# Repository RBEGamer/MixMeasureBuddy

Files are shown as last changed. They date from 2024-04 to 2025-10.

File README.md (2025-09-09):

# MixMeasureBuddy

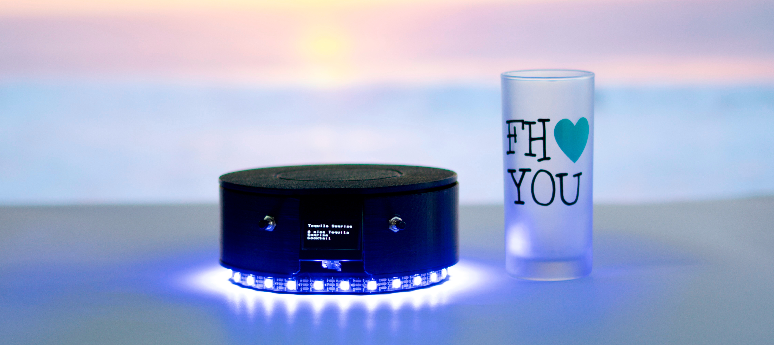
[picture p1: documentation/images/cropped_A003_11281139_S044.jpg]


MixMeasureBuddy's smart cocktail scale revolutionizes home bartending by offering accurate ingredient measurements and a vast library of cocktail recipes personalized to your liquor collection. Enjoy the art of mixology with ease and precision.

Discover the advanced features that set MixMeasureBuddy apart from traditional kitchen scales.

## FEATURES

Discover the advanced features that set MixMeasureBuddy apart from traditional kitchen scales:

* **Open-Source** MixMeasureBuddy is 100% open-source and can be build using a few simple and cheap parts.
* **Connectivity Features** Enjoy seamless integration with a companion webapp for sharing personalized cocktail recipes with other MixMeasureBuddy owners.
* **Offline Usage** Recipes are stored offline and locally on the MixMeasureBerry and can be edited using a text editor
* **User-Friendly Interface** Easily navigate the scale's intuitive interface for effortless cocktail making.
* **Customizable Recipes** Access a plethora of cocktail recipes tailored to your liquor cabinet for endless mixing possibilities.
* **Precision Measurements** Eliminate the guesswork and achieve consistent results with exact ingredient measurements every time.

## BOM

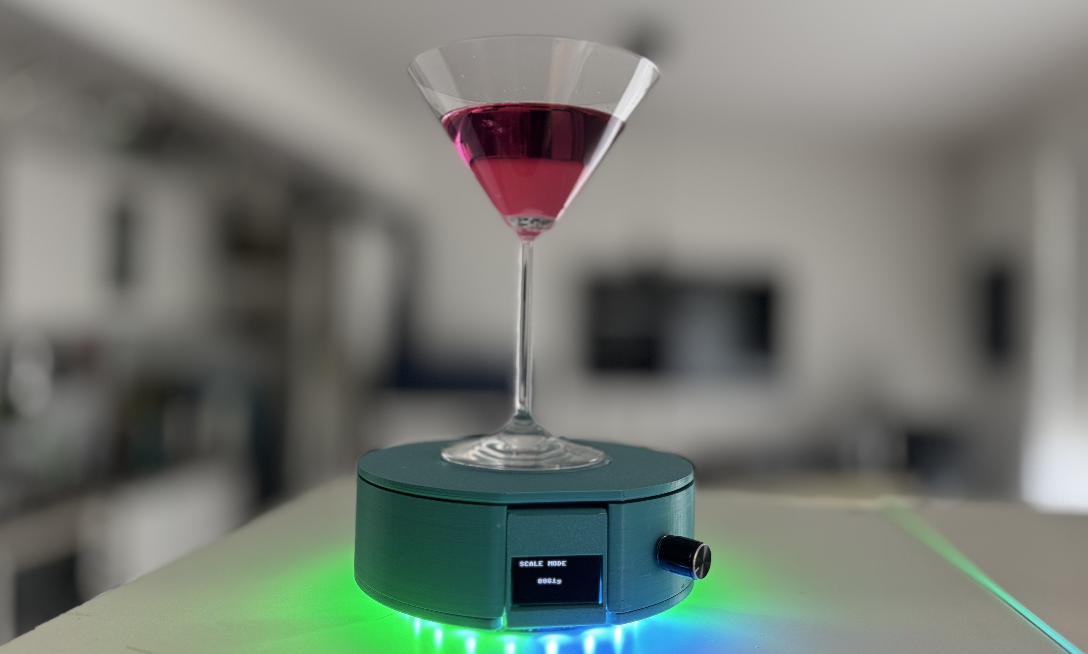
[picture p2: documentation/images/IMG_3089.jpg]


### 3D PRINTED PARTS

**Please read the 3d printing instructions before printing any part!**

* 1x `ring.stl`
* 1x `breadboard_mount.stl`
* 1x `inner_cellplate.stl`
* 1x `hinge.stl`
* 1x `bottom.stl`
* 1x `display_clamp.stl`
* 1x `display_mount.stl`
* 1x `encoder_clamp.stl`

#### CELLPLATE

* 1x `cellplate_<style>.stl`

The top plate exists in three different styles:

* `normal` - plain top plate
* `ring` - with an 82-84mm diameter ring depression in the center to plate a rubber band in it
* `plate` - with an 80mm diameter circular depression to place a rubber sheet in it

The `ring` and `plate` variants offer better grip of the glasses while standing on the platic top plate.

#### BOTTOM PLATE

If a `8mm` wide led strip is used please set the scale of `bottom.stl` to `120%` in **Z** direction.

#### 3D PRINT SETTINGS

* Layer height: `0.2` - `0.4`mm
* Support: `Support on buildplate only`
* Inflill: `20%`

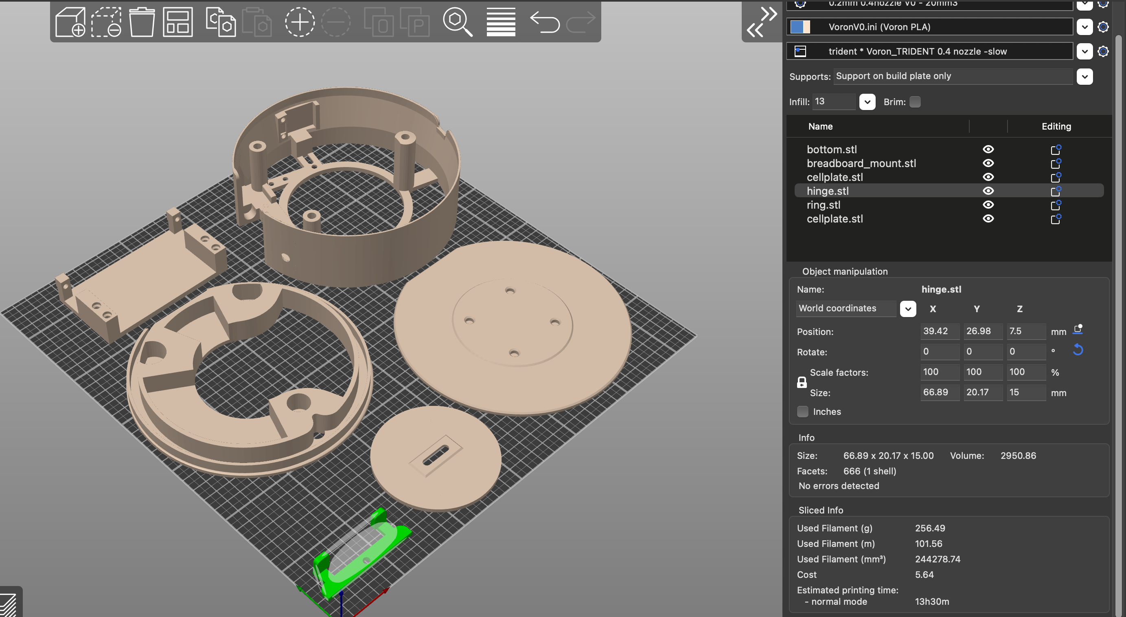
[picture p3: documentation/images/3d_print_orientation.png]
3D printed parts orientation on bed


### MECHANICAL

* 6x `Heat Inserts M3`
* 6x `M3x10 BHCS`
* 4x `M4x10 BHCS` - depends on load cell screw threads
* 3x `Heat Inserts M4`
* 3x `M4x10 BHCS`
* 8x `Cylindrical Magnet D5mm H8mm` or four additional `Heat Inserts M4` + four additional `M4x10 SHCS` to replace the magnets

### MISC

* `Super Glue` - to glue magnets into `inner_cellplate` and `cellplate`

### ELECTRICAL

* 1x `Raspberry Pi Pico` or `Raspberry Pi Pico W`
* 1x `LOAD CELL` with dimensions of `60x12x12mm` and at least `2kg`, for example `YZC-131`
* 1x `HX711`
* 1x `1.3" I2C OLED SSH1306`
* 1x `Encoder` e.g. `KY-040`
* 50cm `WS2812` strip
* Jumperwires  >12x `male-male`, >10x `male-female`
* 1x Breadboard with dimensions of `83 x 55mm`, for example `Mini Breadboard 400 Pin`
* [OPTIONAL] `SPI SD TF Karte Memory Card Shield Modul`
* [OPTIONAL] `Battery Expansion Shield 18650 V3`

### TOOLS

* `Soldering Iron`
* `Hotglue`

## HARDWARE BUILD

### SCHEMATIC

The following diagram shows the internal wiring of the individual components of the `MixMeasureBuddy`.
Only the `Raspberry Pi Pico`, button and the `HX711` are placed on the small breadboard.
The display, `LEDs` and the encoder(-module) are connected with longer cables so that they can be attached to the 3D printed parts at the intended mounting locations.

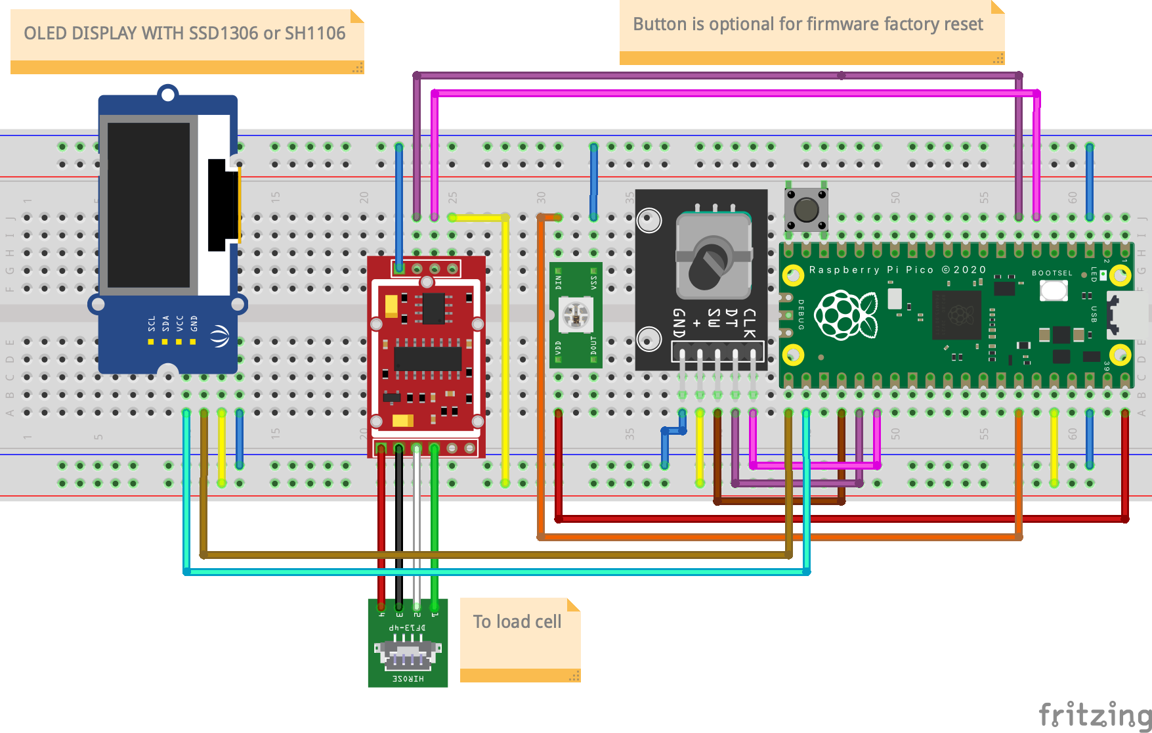
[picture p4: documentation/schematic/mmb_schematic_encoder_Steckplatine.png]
MixMeasureBuddy Schematic


The circuit diagram was created in the Fritzing software. The project can be found under `documenation/schematic/`.
After the function of all parts has been tested, the connections on the breadboard should be fixed with hot glue so that they do not come loose during transportation.

### NOTES

To fix accuracy issues on several `HX711` boards, two addional resistors are needed.
Please refer to this guide: [HX711 – Auswahl und Beschaltung](https://beelogger.de/sensoren/waegezellen_hx711/hx711_beschaltung/#:~:text=HX711%20Modul%20Auswahl,Wägezelle%20und%20einen%20einstellbaren%20Messbrückenverstärker.)

#### [OPTIONAL] SD CARD READER

It is possible to connect an additional SD card reader. This makes it possible to save the recipes on an SD card.  
Please connect the SD card reader to the following pins on the `Raspberry Pi Pico`:

| Raspberry Pi Pico GPIO | SD CARD MODULE GPIO |
|---|---|
| VCC (Pin 36) | 3V3 (OUT) / VCC |
| GND (Pin 18) | GND |
| GP10 | SCK |
| GP8 | MISO |
| GP11 | MOSI |
| GP9 | CS |

No further software changes are needed later on. The systems firmware detects the connected SD card automatically.

#### [OPTIONAL] BATTERY EXPANSION

The `Battery Expansion Shield 18650 V3` can be mounted on the `breadboard_mount.stl` later on.
In oder to connect the `Battery Expansion` to the `Raspberry Pi Pico GPIO` please follow the wiring table below:

| Raspberry Pi Pico GPIO | Battery Expansion |
|---|---|
| VBUS (Pin 40) | 5V OUT |
| GND  (Pin 38) | GND |

## SOFTWARE INSTALLATION

Please check the `Releases` page of this repository for prebuild firmware archives.

To initially flash the software to the `Raspberry Pi Pico`, the `BOOT` button must first be held down when plugging in the `USB` cable.
A new removable disk will then appear on the `PC`. The `firmware.uf2` is then copied to this.
The microcontroller will then restart and the MixMeasureBuddy logo should appear on the display.

If you want to build the software yourself from source or add modifications, please refer to the `SOFTWARE DEVELOPMENT` chapter.

**NOTE** There is an firmware archive with older stable versions located in `src/firmware/build/archive`.

### SOFTWARE UPGRADE

If a old version of the firmwre was already installed on the `Raspberry Pi Pico`, please flash the [flash_nuke.uf2](https://github.com/dwelch67/raspberrypi-pico/blob/main/flash_nuke.uf2) first! This clears all user settings!

**NOTE** Please backup all your stored recipes first!

## MECHANICAL BUILD

FINAL_ASSEMBLY

### 1. DISPLAY MOUNT

DISPLAY_MOUNT_WITH_HEAT_INSERT

* 1x `Heat Inserts M3`
* 1x `M3x10`
* 1x `1.3" I2C OLED SSH1306`
* 4x Jumperwires `male-female`
* 1x `display_clamp.stl`
* 1x `display_mount.stl`

#### INSTRUCTIONS

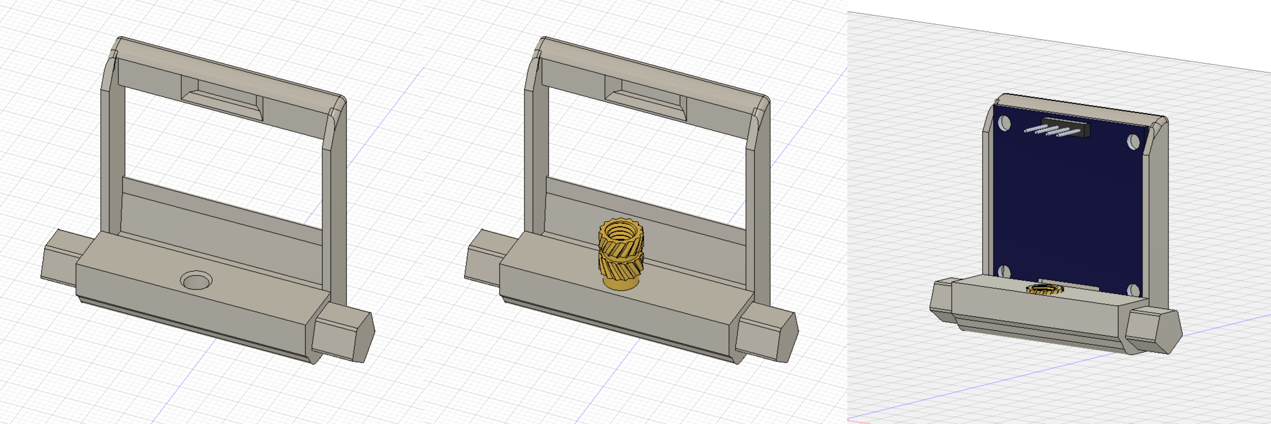
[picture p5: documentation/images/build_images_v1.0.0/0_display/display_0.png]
display_0


1. Insert the `M3 Heat Insert` using a soldering iron into `display_mount`
2. Place the `1.3" I2C OLED SSH1306` display inside `display_mount` 
3. Press the display into place using the `display_clamp` and one `M3x10`
4. Connect four `male-female` jumperwires onto the display header
5. Glue the jumperwire ends and the header together using a drop of hotgleue
6. [OPTIONAL] Lock down the jumperwires using a small zip-tie

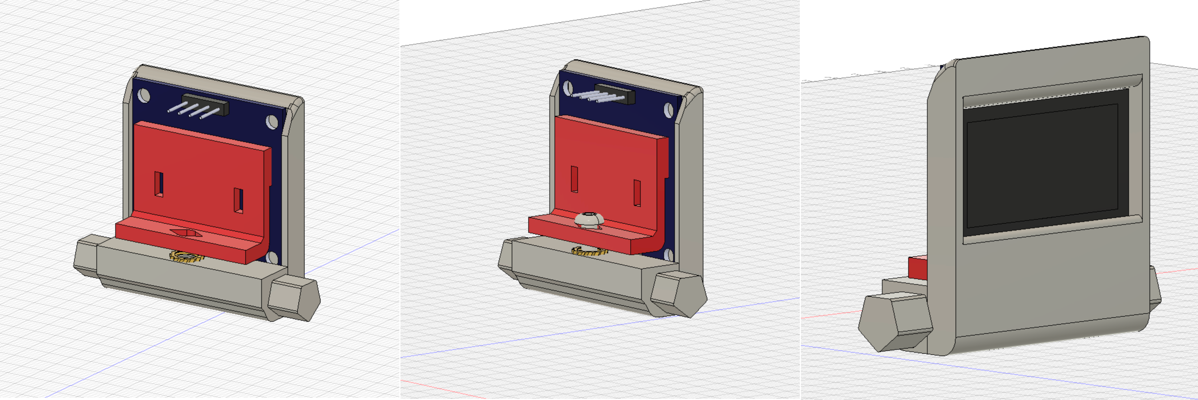
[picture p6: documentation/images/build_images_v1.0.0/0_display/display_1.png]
display_1


### 2. ENCODER MOUNT

* 2x `Heat Inserts M3`
* 1x `M3x10`
* 4x Jumperwires `male-female`
* 1x `Encoder` e.g. `KY-040`
* 1x `encoder_clamp.stl`
* 1x `ring.stl`

#### INSTRUCTIONS

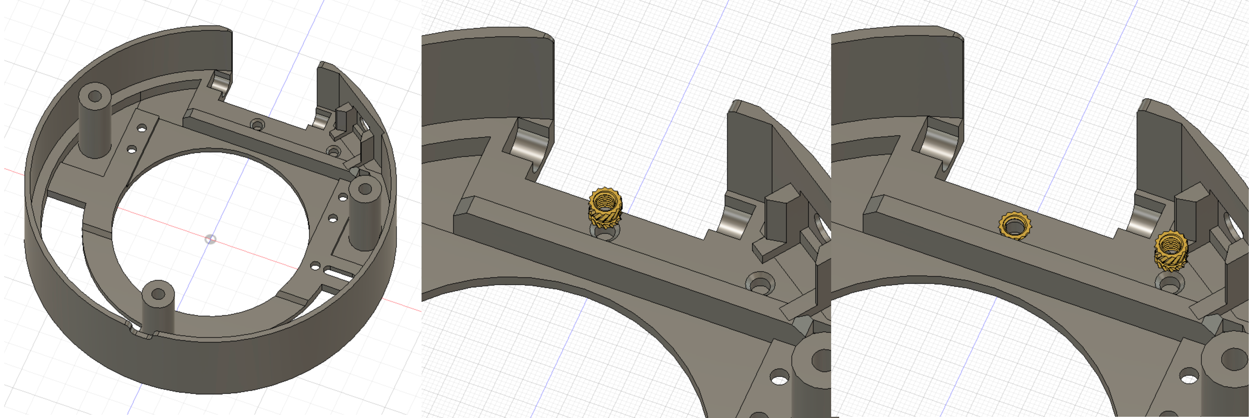
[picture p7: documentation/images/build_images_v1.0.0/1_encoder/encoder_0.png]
1_encoder


1. Connect five `male-female` jumperwires onto the encoder pcb header
2. Insert the two `M3 Heat Inserts` using a soldering iron into `ring` part
3. Insert the encoder pcb into `ring` shell
4. Use the `encoder_clamp` and one `M3x10` to press the encoder into the `ring`

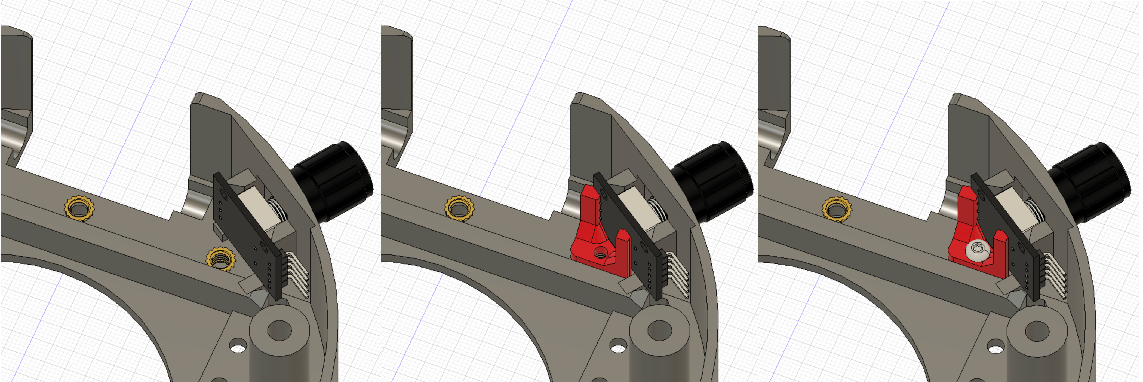
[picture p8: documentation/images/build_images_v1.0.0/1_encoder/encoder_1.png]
1_encoder


### 3. ASSEMBLE DISPLAY AND RING PARTS

* 1x `M3x10`
* 1x `hinge.stl`

#### INSTRUCTIONS

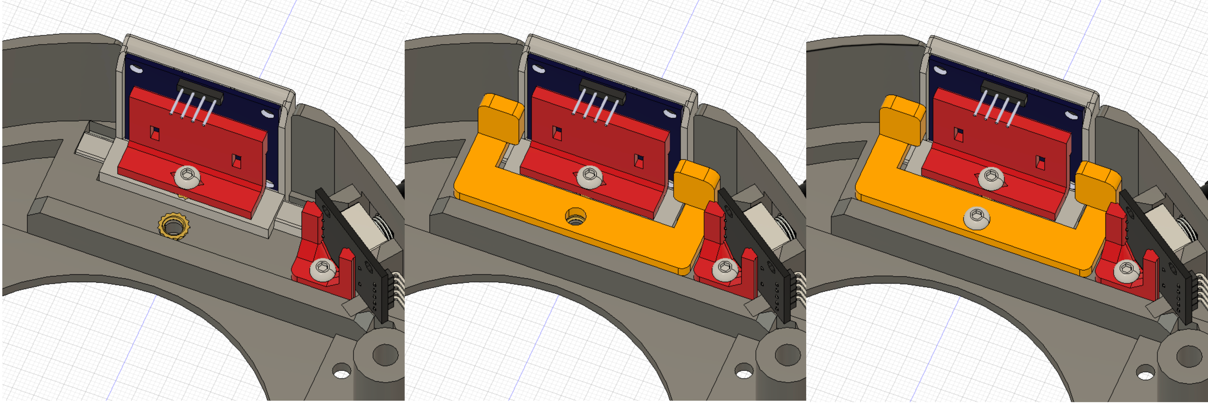
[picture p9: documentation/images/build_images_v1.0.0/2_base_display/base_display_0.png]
2_base_display
 

* Place the display assembly in the indentation
* Use the `hinge` and  one `M3x10` to press the assembly into the `ring`

### 3. LOADCELL

* 4x `M4x10` - depends on load cell screw threads
* 4x `Cylindrical Magnet D5mm H8mm`
* 1x `LOAD CELL`

* 1x `inner_cellplate.stl`

#### INSTRUCTIONS

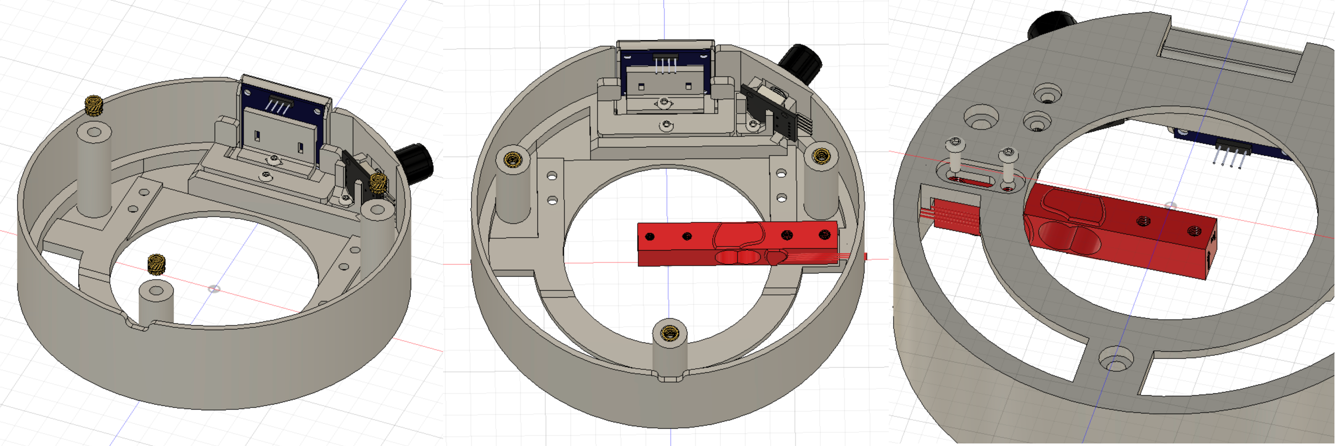
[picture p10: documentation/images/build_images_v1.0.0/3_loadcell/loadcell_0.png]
3_loadcell
 

1. Insert the three `M4 Heat Inserts` using a soldering iron into `ring` part
2. Screw the loadcell using two `M4x10` screws into the `ring`
3. Use the remaining `M4x10` screws to mount the `inner_cellplate` on the load cell arm, in the center of the `ring` cutout
4. Glue four magnets into `inner_cellplate`

**NOTE** The cables from the load cell are facing towards the shell of the `ring`

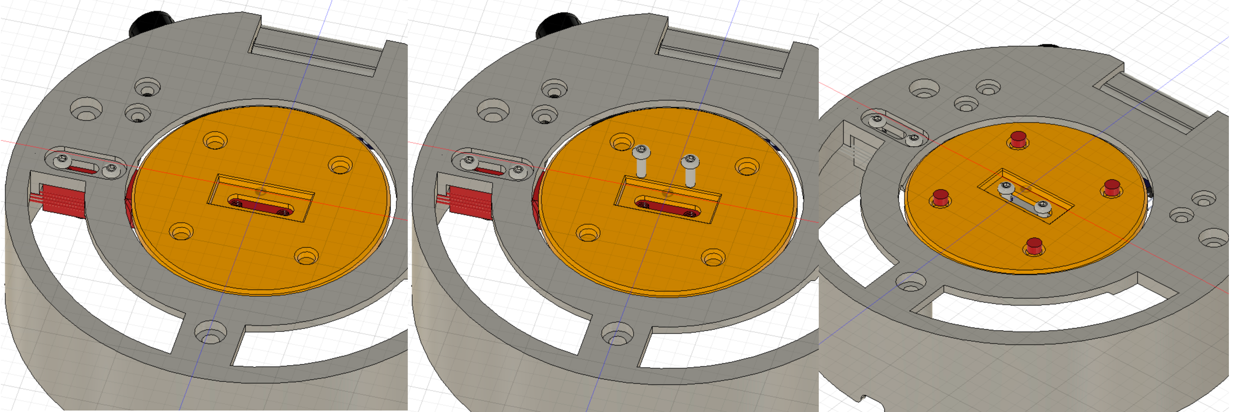
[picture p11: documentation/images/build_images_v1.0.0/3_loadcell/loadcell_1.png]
3_loadcell
 

### 4. BREADBOARD

ELECTRONICS_BAY_COMPONENTS

* 4x `Heat Inserts M3`
* 4x `M3x10 BHCS`
* 1x `ASSEMBLED BREADBOARD`
* 1x `breadboard_mount.stl`

#### INSTRUCTIONS

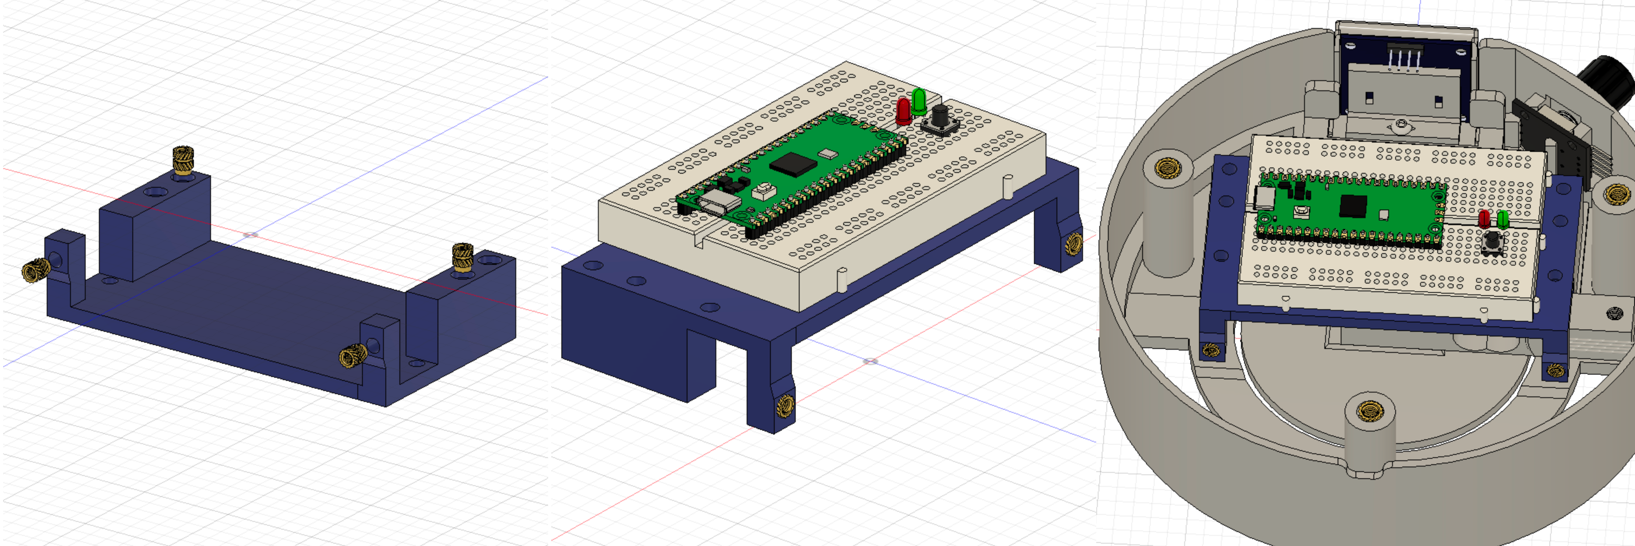
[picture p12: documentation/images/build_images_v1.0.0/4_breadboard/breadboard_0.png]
4_breadboard
 

1. Insert the four `M3 Heat Inserts` using a soldering iron into `breadboard_mount` part
2. [OPTIONAL] Screw the `Battery Expansion Shield 18650 V3` into the side using two `M3x10`
3. Remove the protective film from the breadboard bottom side and place it ontop `breadboard_mount`stl`
4. Use the remaining two `M3x10` screws to fix `breadboard_mount` and `ring` together into place

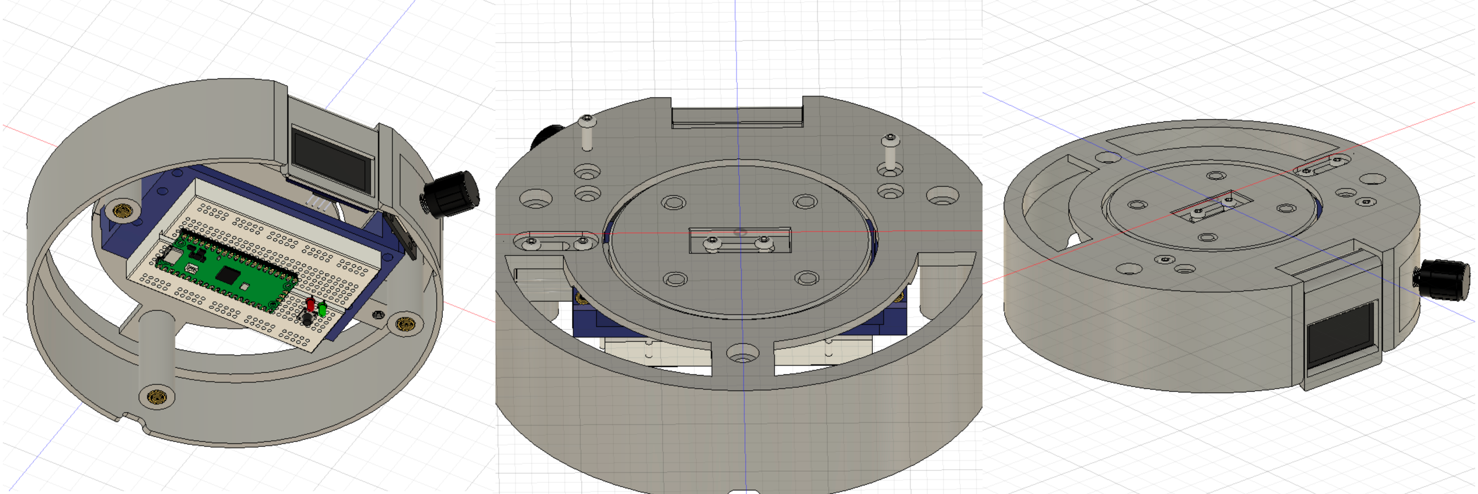
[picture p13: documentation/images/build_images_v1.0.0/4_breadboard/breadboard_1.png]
4_breadboard
 

**NOTE** Please connect all remaining components (`Encoder`, `Display`, ...) to the breadboard. See chapter `SCHEMATIC` again.
**NOTE** Its a good time to test the electronics again! Please refer to the `SOFTWARE INSTALLATION` chapter.

### 5. BOTTOM

* `WS2812` strip
* 3x `M4x10 SHCS`
* 3x  Jumperwire `male-male`
* 1x `bottom.stl`

#### INSTRUCTIONS

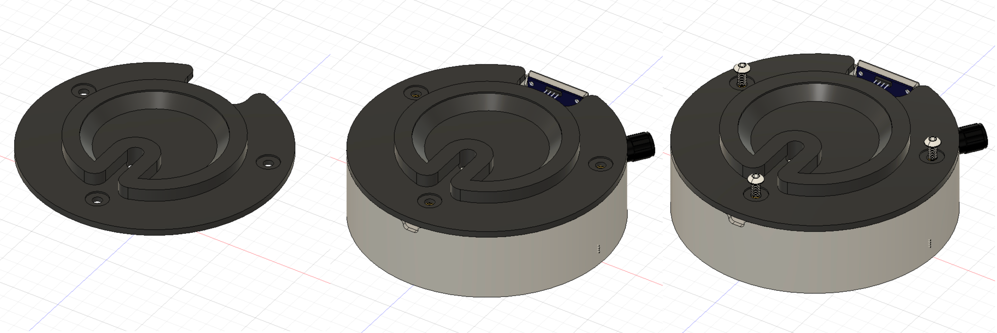
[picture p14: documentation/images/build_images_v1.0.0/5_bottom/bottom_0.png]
5_bottom
 

1. Solder three `male-male` jumperwires onto the `WS2812` strip (`VCC`, `GND`, `DIN`)
2. Remove the protective film from the `WS2812` strip and place them on the center ring of the `bottom`
3. Screw the `bottom` using the three `M4x10` screws onto `ring` assembly.

**NOTE** Make sure that the `Micro USB` is going thought opening between `bottom`  and `ring`.
**NOTE** If no `Battery Expansion Shield 18650 V3` is installed, please insert a `Micro USB` cable into the `Raspberry Pi Pico` before attaching the `bottom`.

### 6. CELLPLATE

* 4x `Cylindrical Magnet D5mm H8mm` or 4x `M4x6.x mm` heat inserts + 4x `M4x10 SHCS` to replace the magnets
* 1x `cellplate.stl`

#### INSTRUCTIONS

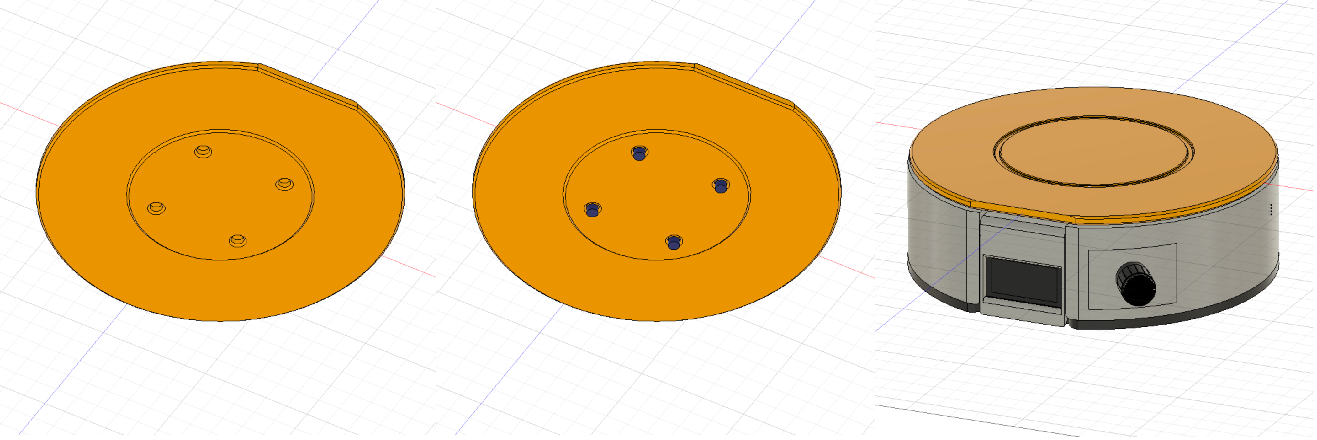
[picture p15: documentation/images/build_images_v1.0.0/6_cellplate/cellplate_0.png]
6_cellplate
 

##### USING MAGNETS
1. Glue four magnets into `cellplate`
2. Place the `cellplate` on the `inner_cellplate`

**NOTE** Please ensure that the magnets in the two parts `cellplate`, `inner_cellplate` attract each other on opposite sides

##### USING HEAT INSERTS

1. Insert the `heatinserts` in the four holes of the `cellplate`
2. 
3. Place the `cellplate` on the `inner_cellplate`
4. Align the flat edge of the `cellplate` with the display and use the four `M4x10 SHCS` screws to connect the `cellplate` with `inner_cellplate`

# USAGE

Once the hardware has been set up and the software has been flashed to the microcontroller, the system can be set up for the first time.
The basic operation and calibration of the system is described below.

## MENU NAVIGATION

After switching on the power supply, e.g. via a power bank, the main menu appears on the display immediately after the logo screen.
Navigation in the system is very easy thanks to the rotary encoder. 
The right and left rotation of the encoder can be used to scroll through the separate menu entries.
If you want to enter / activate a menu item, simply press the button on the encoder.
To exit a menu/recipe, the encoder button must be held down for at least half a second.

## CALIBRATION

If the scales menu or a recipe is now called up. The weighing results can deviate significantly from reality.
This is due to the installation direction of the load cell, its mounting and other factors.
The menu item `CALIBRATION` is provided for this purpose.
For this process, the scale is measured with and without weight and the corresponding correction factors are determined.

A known weight with at least `50g` is therefore required. This can be a glass of water, for example, which has previously been measured with a kitchen scale.

After starting the calibration routine, the user is guided through the following steps one after the other:

* Measure empty scale
* User enters weight of calibration object
* User places calibration object on scale
* User removes calibration object if shown by display

**NOTE** If the scales light up red, please `DONT MOVE OR TOUCH`.

**NOTE** The `IKEA POKAL` glass has a weight of 390g (empty) :)

## RUN A RECIPE

## ADDING CUSTOM RECIPES

A recipe in the context of the MixMeasureBuddy consists of a JSON object in a .recipe file. This contains meta data such as the name and description of the recipe as well as a series of instructions that the user should execute to complete the recipe. The following instruction types can be used for this purpose:

* SCALE - Weigh until x grams reached
* WAIT - Wait x seconds
* CONFIRM - Confirm that it has been done.

There are two ways to create a new recipe manually:

### BY USING recipe.py CLASS

* Create a new empty folder
* Copy the `src/firmware/src/static_modules/recipe.py` into the new created folder
* Create a new `MyRecipe.py` file with the following content Python script below
* Change the name, description and steps according your imagination

```python
# SEE example_recipes.py FOR FURTHER / DETAILED EXAMPLES
import recipe

example_recipe: recipe.recipe = recipe.recipe("Tequila Sunrise", "A nice Tequila Sunrise Cocktail", "1.0.0", ["Tequila"])
# ADD A SCALE STEP: ADD x g TO THE GLASS
example_recipe.add_step(recipe.recipe_step.create_scale_step(_ingredient_name="White Tequila", _target_value = 10))
# ADD A SCALE STEP: ADD x g TO THE GLASS
example_recipe.add_step(recipe.create_scale_step(_ingredient_name="Orange Juice", _target_value = 120))
# ADD CONFIRM STEP: ADD ICE AND CONFIRM WITH A BUTTON PRESS
example_recipe.add_step(recipe.create_scale_step(_ingredient_name="Ice", _current_step_text="Add Ice"))
# ADD A SCALE STEP: ADD x g TO THE GLASS
example_recipe.add_step(recipe.create_scale_step(_ingredient_name="Grenadine", _target_value = 40))
# ADD A WAIT STEP:  WAIT x SECONDS
example_recipe.add_step(recipe.create_scale_step(_current_step_text="Wait for settle down", _target_value = 10))

# EXPORT THE RECIPES AS JSON BASE .RECIPE FILE
with open("MyRecipe.recipe, "w") as file:
  file.write(json.dumps(example_recipe.to_dict()))
# COPY OVER THE .RECIPE FILE TO THE SCALE
```

Run the 

```bash
$ python MyRecipe.py
$ cat MyRecipe.recipe
```

This scripts created a new `MyRecipe.recipe` file. The content is a `JSON` strucutre which is compatible with the recipe system of the scale.

### CREATEING A JSON BASED .recipe FILE

```json
{
    "filename": "Tequila_Sunrise.recipe",
    "name": "Tequila Sunrise",
    "steps": [{
        "text": "",
        "ingredient": "White Tequila",
        "amount": 10,
        "action": 0
    }, {
        "text": "",
        "ingredient": "Orange Juice",
        "amount": 120,
        "action": 0
    }, {
        "text": "Add Ice",
        "ingredient": "Ice",
        "amount": -1,
        "action": 1
    }, {
        "text": "",
        "ingredient": "Grenadine",
        "amount": 40,
        "action": 0
    }, {
        "text": "Wait for settle down",
        "ingredient": "",
        "amount": 10,
        "action": 2
    }],
    "description": "A nice Tequila Sunrise Cocktail",
    "version": "1.0.0"
}
```

### COPY RECIPES TO SCALE

To access the files and the Micropython environment on the scale directly, its possible to use these two example programs below:

* [Thonny](https://github.com/thonny/thonny/)
* [rshell](https://github.com/dhylands/rshell)

In this example, a previously created recipe file is to be copied to the `MixMeasureBuddy` so that it can be used.
After connecting the flashed `MixMeasureBuddy` to a host PC using a USB cable, run the following commands in order to transfer the `.recipe` file.

#### THONNY

For installation, please refer to the installation guid on the website [INSTALL_THONNY](https://thonny.org).

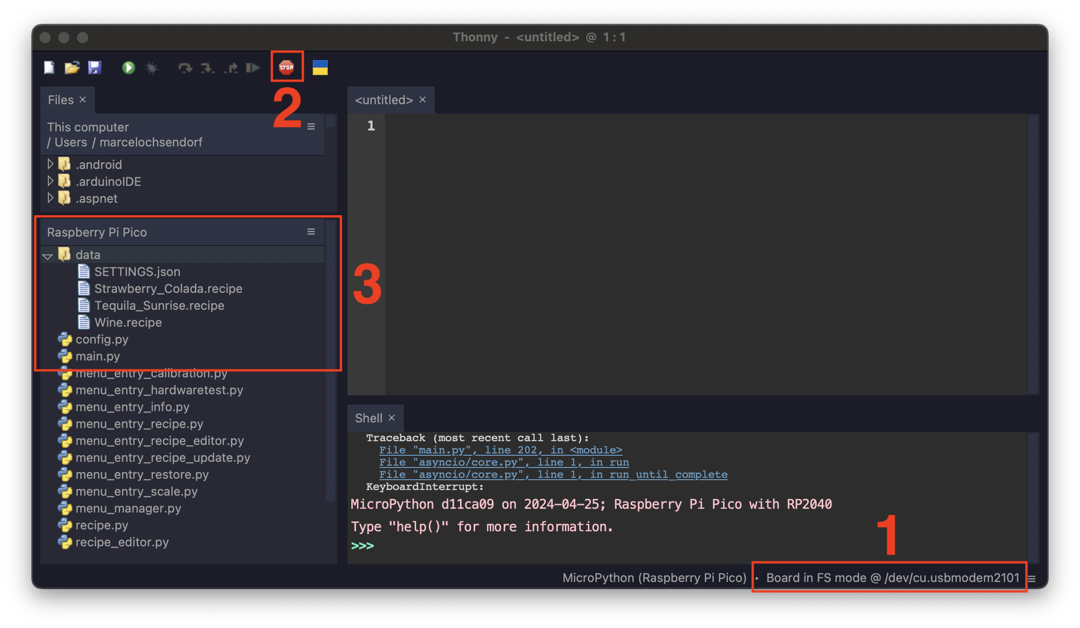
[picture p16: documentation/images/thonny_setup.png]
Thonny_Files_Access


The image shows the steps in order to connect the `MixMeasureBuddy` and access its files:

1. Select the board
2. Connect to python repl running on the board
3. Use the file explorer to add/edit/remove files 

#### RSHELL

```bash
# INSTALL RSHELL
$ sudo pip3 install rshell

#TEST CONNECTION
$ rshell
# OR
$ rshell -p /dev/ttyUSB0
# COPY
$ rshell cp MyRecipe.recipe /data/MyRecipe.recipe
```

The recipe is now stored on the `MixMeasureBuddy`. Powercycle the device to load the new recipes!

### USER CONFIGURATION

If a `Raspberry Pi Pico W` is used, its possible to use the recipe editor and the recipe api update functions.
Here the wifi credentials needs to be set using the `SETTINGS.json` file on the scale.
Please use the same procedure described above to edit files on the scale filesystem.

# FIRMWARE DEVELOPMENT

The microcontroller firmware of the `Raspberry Pi Pico` was created in micropython and is automatically created with the pre-built image. 
The source code files are located in the folder `src/firmware_rp2040` and the Python source code files in the folder `src/firmware_rp2040/src`.
The program `Thonny` can be used to adapt the software directly on the scale.

## DIFFERENT HARDWARE CONFIG

The global hardware configuration (used display type, pin definitions and other settings) are stored in the `Config.py` loacted in the virtual filesystem.
Its possbile to modify this file using the `REPL` or` Thonny` as described above.

## STRUCTURE

The entry point of the software is in the `main.py`, which is called by the custom pre-boot script `boot.py`. The general configuration of the hardware (e.g. which pins the buttons are connected to) is done in the `config.py` file.

The control of the hardware components is done in the files:

* `ui.py` - UI system + display control
* `ledring.py` - LED effects for the LED ring
* `Scales.py` - readout of the HX711
* `settings.py`- filesystem access for writing/reading recipe files and settings

All these classes can be easily called from all other scripts using the singleton pattern. This makes integration very simple and uniform:

```python
import ledring
import ui
import Scale
# CLEAR DISPLAY
ui().clear()
# SET LED RING
ledring().set_neopixel_full_hsv(ledring().COLOR_PRESET_HSV_H__BLUE)
# GET CURRENT SCALE MEASUREMENT
ScaleInterface().get_current_weight()
```

The individual menus are designed as a plug-in system. This allows you to quickly create your own extensions.
The plugins are designated in the system with the prefix `menu_entry_*.py` and the functions are derived from the base class `menu_entry.py`.
This consists of an `activate`, `teardown` and `update` function, which are called accordingly when the corresponding menu entry is called.

```python
class menu_entry_MyPlugin(menu_entry.menu_entry):

    def __init__(self):
        super().__init__("MyPlugin", "My nice plugin")
    # WILL BE CALLED IF USER SELECTS PLUGIN
    def preview(self):
        print("preview {}".format(self.name))
        ui().show_recipe_information(self.name, self.description)
    
    # WILL BE CALLED IF USER ACTIVATES PLUGIN
    # E.G. DO SETUP STUFF
    def activate(self):
        print("activate {}".format(self.name))
        ui().show_titlescreen()

    # WILL BE CALLED IF USER EXISTS PLUGIN
    # E.G. DELETE RESOURCES
    def teardown(self):
        print("teardown {}".format(self.name))

    # WILL BE CALLED IF A USER PRESSES A BUTTON, EVERY SECOND OR IF THE WEIGHT ON LOAD CELL CHANGES
    def update(self, _system_command: system_command.system_command):
        
        if _system_command.type == system_command.system_command.COMMAND_TYPE_NAVIGATION:
            if _system_command.action == system_command.system_command.NAVIGATION_ENTER: #  OK BUTTON
                pass
            elif _system_command.action == system_command.system_command.NAVIGATION_LEFT: # NEXT BUTTON
                pass
            elif _system_command.action == system_command.system_command.NAVIGATION_RIGHT: # PREV BUTTON
                pass

        elif _system_command.type == system_command.system_command.COMMAND_TYPE_SCALE:
              print("CURRENT WEIGHT: {}".format(_system_command.value))
  
        elif _system_command.type == system_command.system_command.COMMAND_TYPE_TIMER_IRQ:
              print("ELAPSED TIME SINCE LAST CALL: {}".format(_system_command.value))
           
```

To add the plugin, import the module in `main.py` and add the class into the menu tree:

```python
from menu_entry_MyPlugin import menu_entry_MyPlugin
menu_manager.menu_manager().add_subentries(menu_entry_MyPlugin.menu_entry_MyPlugin())
```

Its also possible to add sub-menus using the `menu_entry_submenu` plugin:

```python
# CREATE SUBMENU WITH CUSTOM TITLE
submenu: menu_entry_submenu.menu_entry_submenu = menu_entry_submenu.menu_entry_submenu("SYSTEM", "ACCESS SYSTEM SETTINGS")
# ADD MENU ENTRIES TO THE SUBMENU
submenu.add_subentries(menu_entry_calibration.menu_entry_calibration())
submenu.add_subentries(menu_entry_calibration.menu_entry_calibration())
submenu.add_subentries(menu_entry_calibration.menu_entry_calibration())
# ADD THE SUBMENU TO THE MAIN MENU
menu_manager.menu_manager().add_subentries(submenu)
```

## FIRMWARE IMAGE

To create a finished and complete firmware image, the folder `src/firmware_rp2040` contains a bash script which creates the images using `Docker` for the `Raspberry Pi Pico` and `Raspberry Pi Pico W` and the required boot configurations.

```bash
# INSTALL AND RUN DOCKER https://docs.docker.com/engine/install/
$ cd src/firmware_rp2040
$ bash ./build_firmware_docker.sh
# RESULTS ARE LOCATED IN THE build FOLDER
```

## BUILD SYSTEM BACKGROUND

One problem was how to build and distribute the Micropython images automatically via e.g. GitHub.
The way documented by Micropython does not allow the user to change the code and data after building the u2f, because they are permanently written to the flash (static/lib) fodlers.
That's why the complicated build process was created using a Docker image that installs a pre application boot procedure, so that the user source code to the Python file system during the first boot.
This way, functions can be easily added/modified by the user and at the same time the finished software can be easily distributed.

# TODO

* Cocktail database webapp - `src/webapp`

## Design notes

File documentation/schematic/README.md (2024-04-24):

# SCHEMATIC

## FRITZING PART SOURCES

* `KY-040_AZ_Rotary_encoder_v0.fzpz` - https://forum.fritzing.org/t/ky-040-rotary-encoder-breakout-board-part/11073
* `Raspberry-Pi-Pico-tht.fzpz` - https://forum.fritzing.org/t/looking-for-raspberry-pi-pico-part/11915

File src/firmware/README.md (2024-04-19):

# MIX MEASURE BUDDY FIRMWARE

## BUILD MICROPYTHON FIRMWARE WITH CUSTOM MMB CODE USING DOCKER

```bash
# USING DOCKER
$ ./build_firmware_docker.sh
# FIRMWARE FILES FOR EACH SET MANIFEST
$ ls -la $PWD/build
```

##

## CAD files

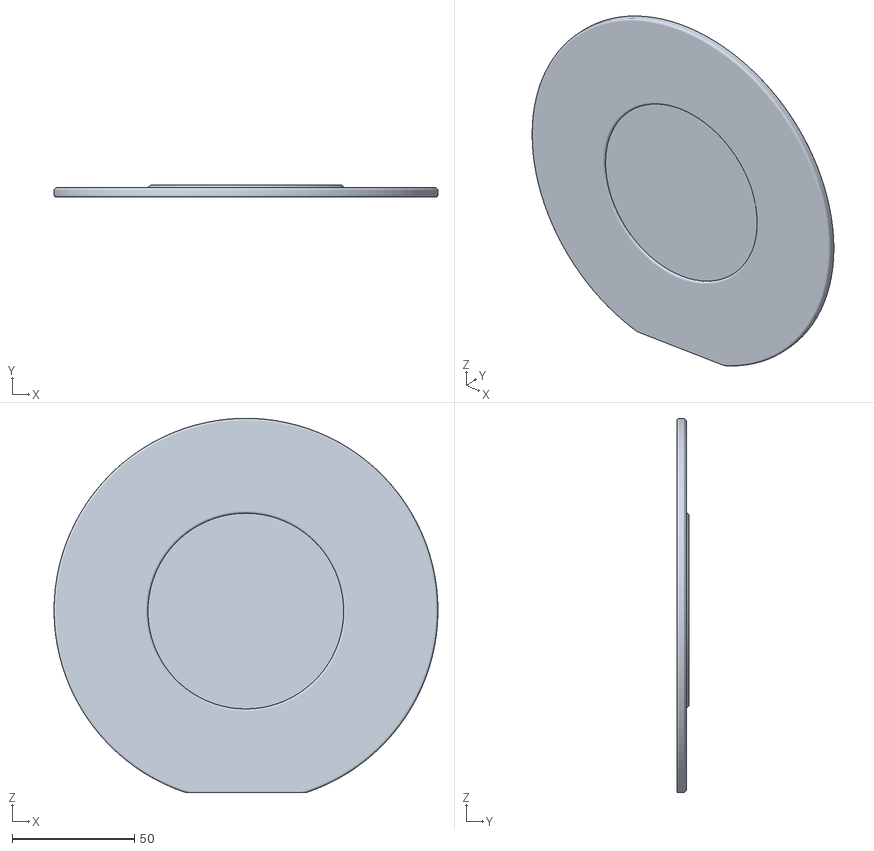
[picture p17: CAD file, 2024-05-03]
src/cad/v1.0.0/stl/cellplate_complete.stl
157.0 x 5.00 x 153.0

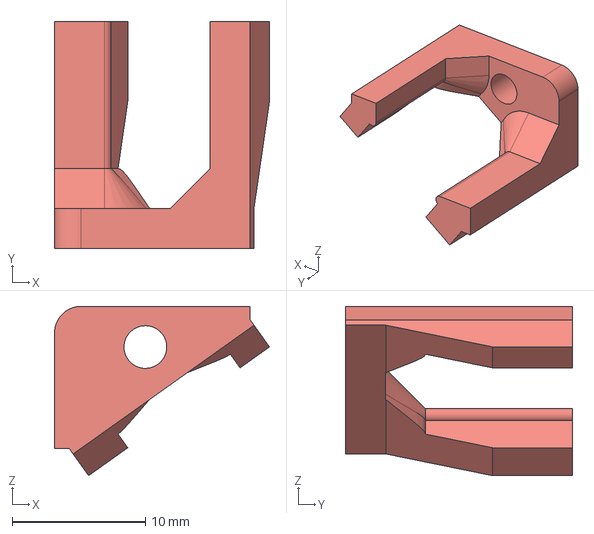
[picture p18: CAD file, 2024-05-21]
src/cad/v1.0.0/encoder_clamp.step
16.1 x 17.0 x 12.7 mm

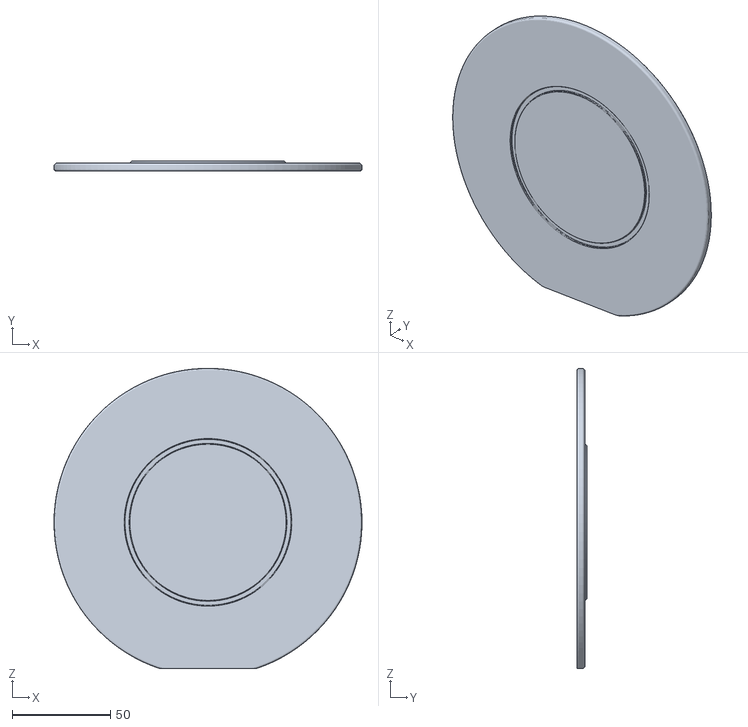
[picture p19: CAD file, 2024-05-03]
src/cad/v1.0.0/stl/cellplate_with_ring.stl
157.0 x 5.00 x 153.0

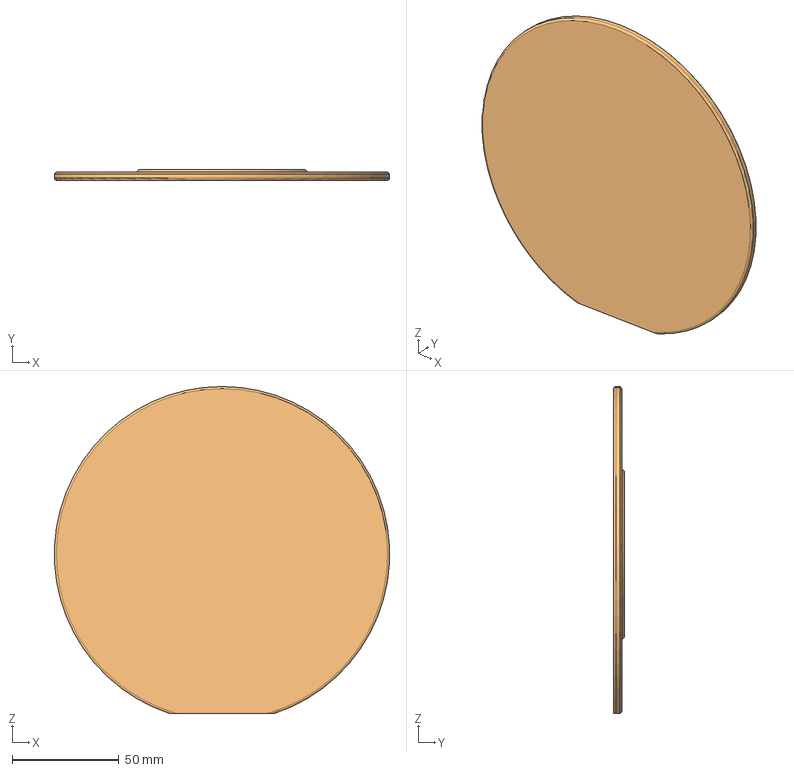
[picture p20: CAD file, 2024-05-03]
src/cad/v1.0.0/cellplate.step
156.8 x 5.00 x 153.1 mm

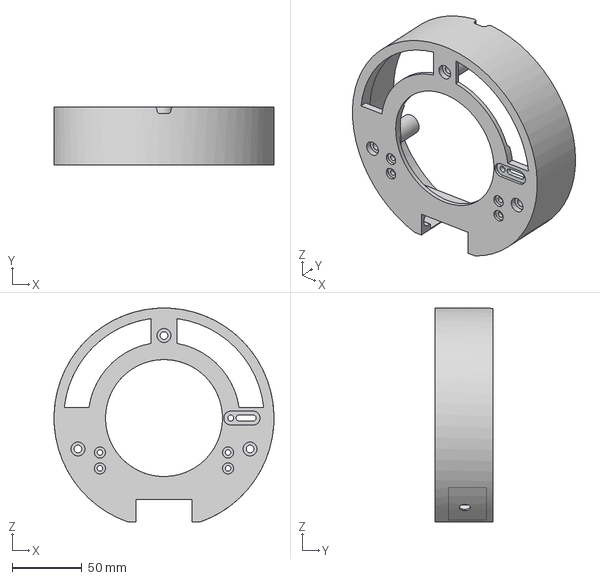
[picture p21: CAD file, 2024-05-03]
src/cad/v1.0.0/ring.step
158.0 x 42.0 x 153.6 mm

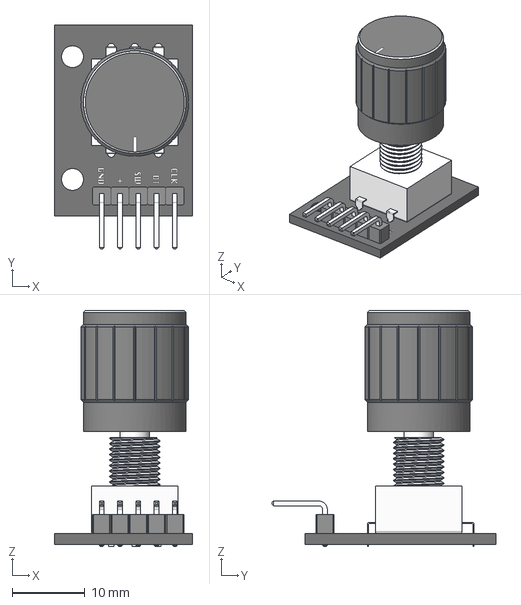
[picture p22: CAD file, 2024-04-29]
src/cad/v1.0.0/Rotary Encoder - KY-040 v1.step
19.0 x 30.8 x 32.4 mm

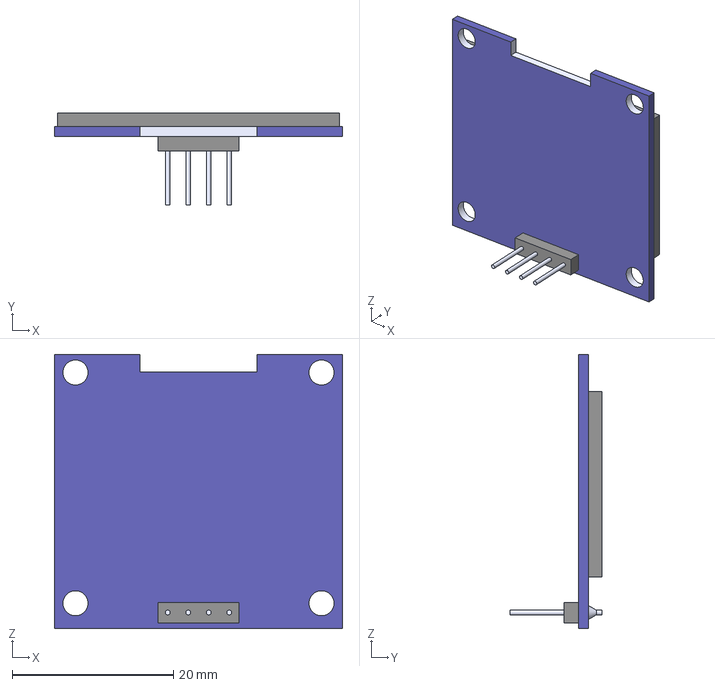
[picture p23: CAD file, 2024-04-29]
src/cad/v1.0.0/Display_OLED_SSD1306_1.3inch v1.step
35.7 x 11.4 x 34.0 mm

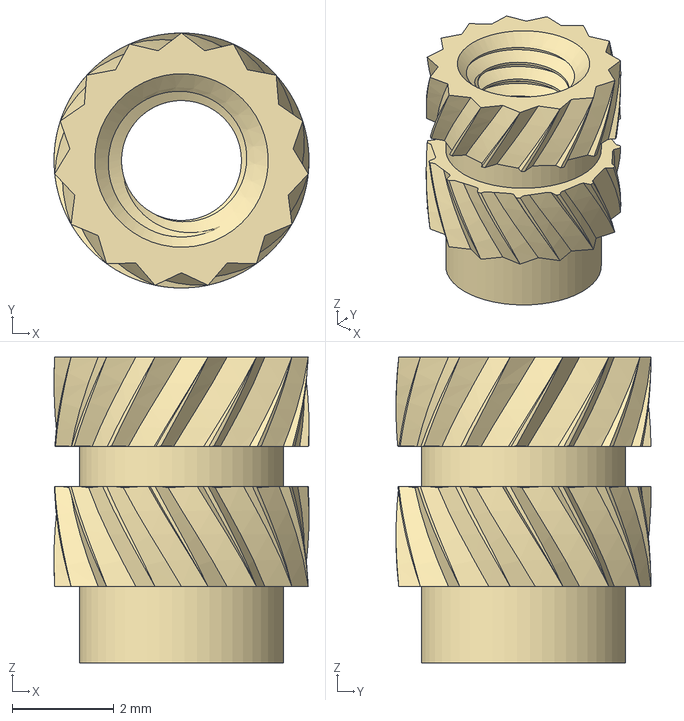
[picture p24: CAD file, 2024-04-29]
src/cad/v1.0.0/Insert M3 D5 L5mm v1.step
5.00 x 5.00 x 6.00 mm

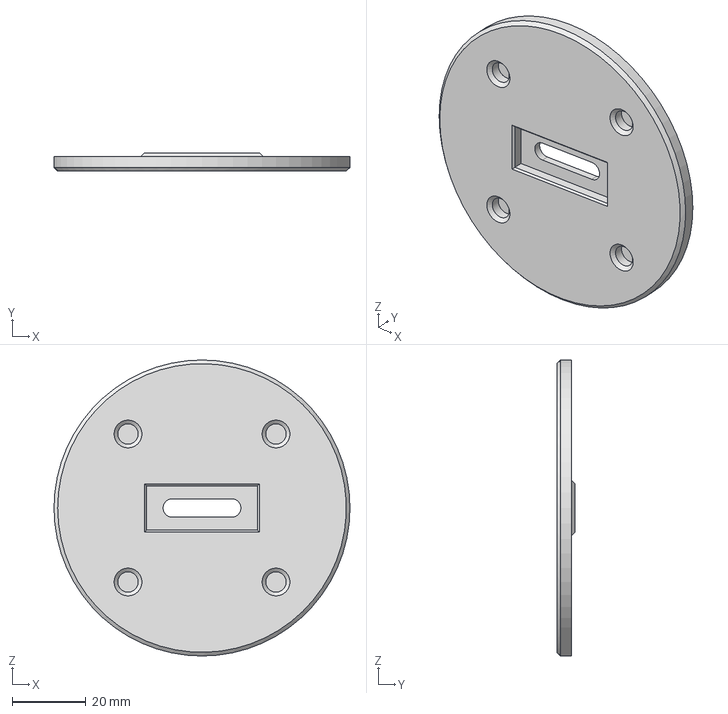
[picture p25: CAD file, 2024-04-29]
src/cad/v1.0.0/inner_cellplate.step
80.0 x 5.00 x 80.0 mm

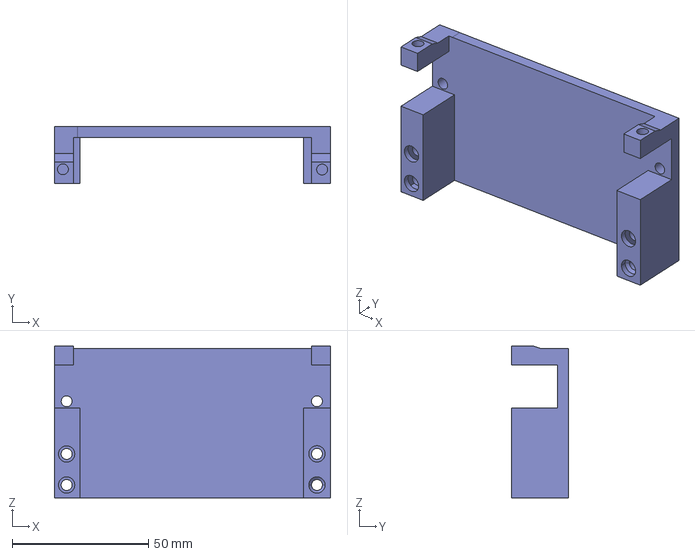
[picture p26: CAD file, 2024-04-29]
src/cad/v1.0.0/breadboard_mount.step
101.4 x 21.0 x 55.9 mm

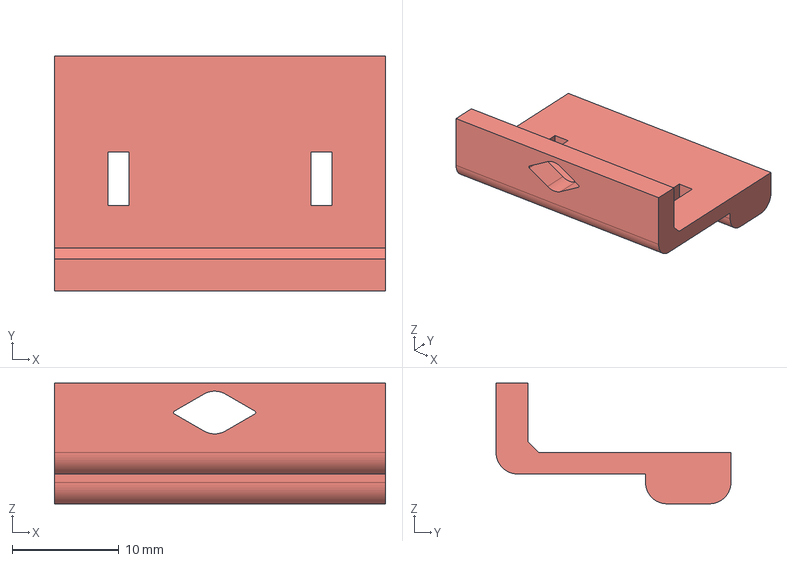
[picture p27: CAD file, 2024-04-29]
src/cad/v1.0.0/display_clamp.step
31.0 x 22.0 x 11.3 mm

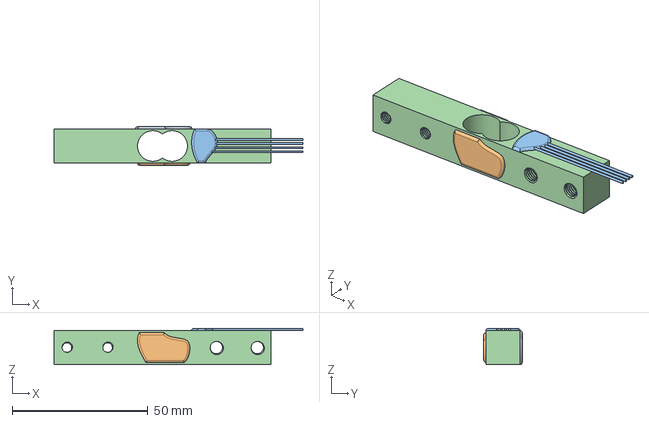
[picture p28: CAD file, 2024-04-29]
src/cad/v1.0.0/Loadcell-1kg-No Name v1.step
91.8 x 14.2 x 13.4 mm

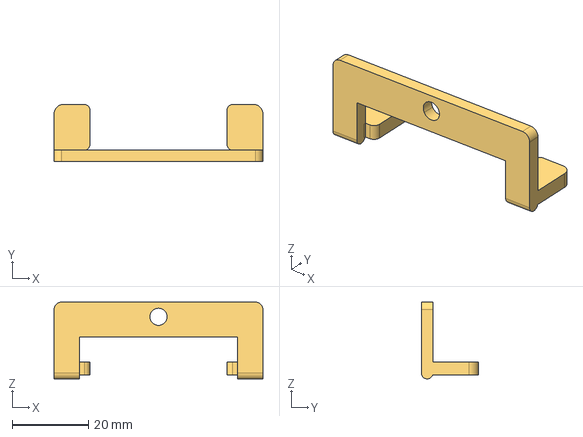
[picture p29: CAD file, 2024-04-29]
src/cad/v1.0.0/hinge.step
54.9 x 15.0 x 20.2 mm

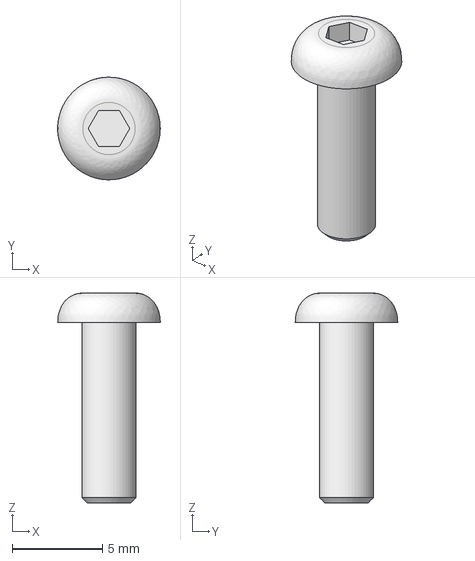
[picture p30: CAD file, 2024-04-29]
src/cad/v1.0.0/hex_socket_button_head_M3x10 v1.step
5.69 x 5.70 x 11.7 mm

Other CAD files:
src/cad/v1.0.0/stl/cellplate_normal.stl
src/cad/v1.0.0/bottom.step
src/cad/v1.0.0/display_mount.step
src/cad/v1.0.0/Insert M5 D7 L9.5mm v1.step
src/cad/v0.1.0/mixmeasurebuddy_v33.f3z
src/cad/v0.1.0/stl/bottom.stl
src/cad/v0.1.0/stl/breadboard_mount.stl
src/cad/v0.1.0/stl/cellplate.stl
src/cad/v0.1.0/stl/display_clamp_SSH1106.stl
src/cad/v0.1.0/stl/display_mount_SSH1106.stl
src/cad/v0.1.0/stl/hinge.stl
src/cad/v0.1.0/stl/inner_cellplate.stl
src/cad/v0.1.0/stl/ring.stl
src/cad/v1.0.0/breadboard_case v1 v1.step
src/cad/v1.0.0/hex_socket_button_head_M3x10 v1 (5).step
src/cad/v1.0.0/stl/bottom.stl
src/cad/v1.0.0/stl/breadboard_mount.stl
src/cad/v1.0.0/stl/display_clamp.stl
src/cad/v1.0.0/stl/display_mount.stl
src/cad/v1.0.0/stl/encoder_clamp.stl
src/cad/v1.0.0/stl/hinge.stl
src/cad/v1.0.0/stl/inner_cellplate.stl
src/cad/v1.0.0/stl/ring.stl

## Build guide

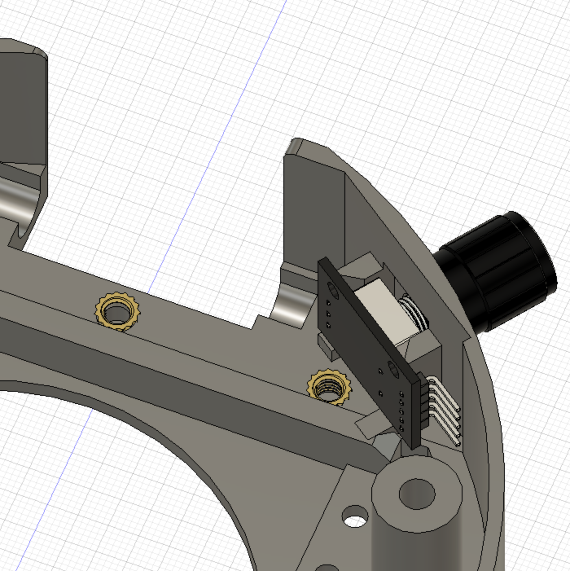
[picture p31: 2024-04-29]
documentation/images/build_images_v1.0.0/1_encoder/base_enc_D.png

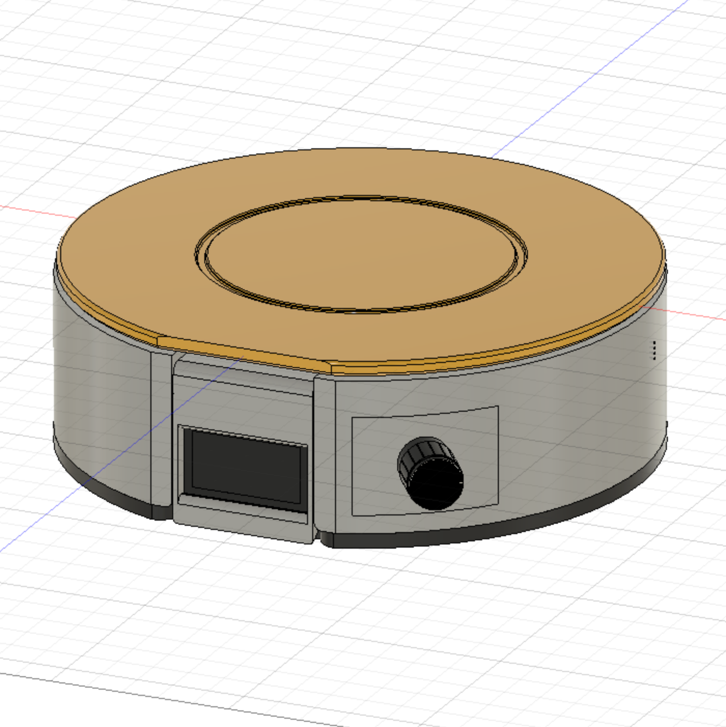
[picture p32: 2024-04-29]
documentation/images/build_images_v1.0.0/6_cellplate/cellplate_C.png

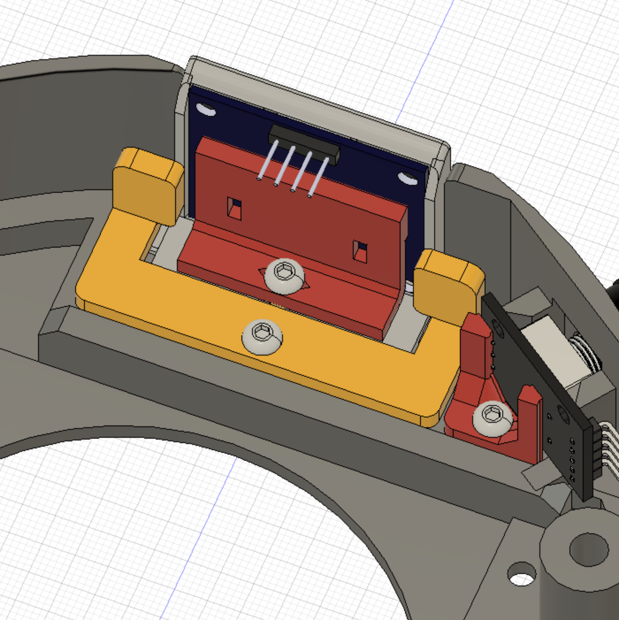
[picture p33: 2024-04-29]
documentation/images/build_images_v1.0.0/2_base_display/base_disp_C.png

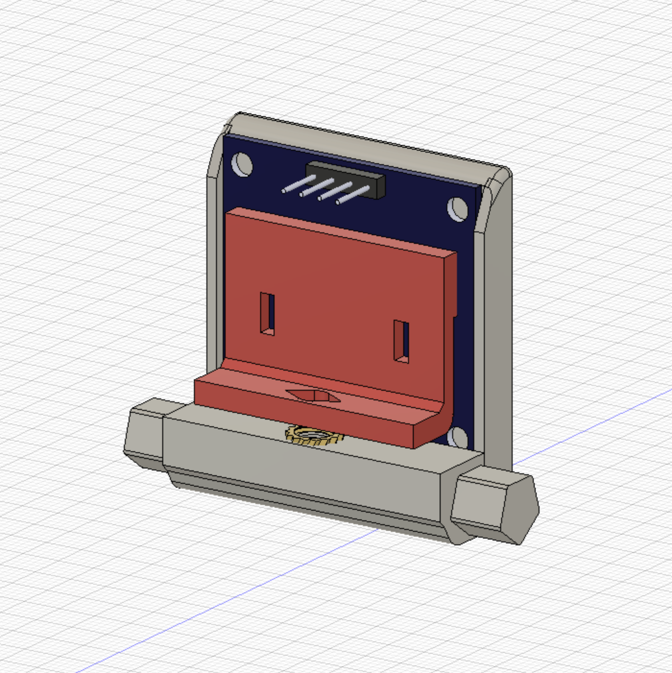
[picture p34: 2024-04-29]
documentation/images/build_images_v1.0.0/0_display/disp_D.png

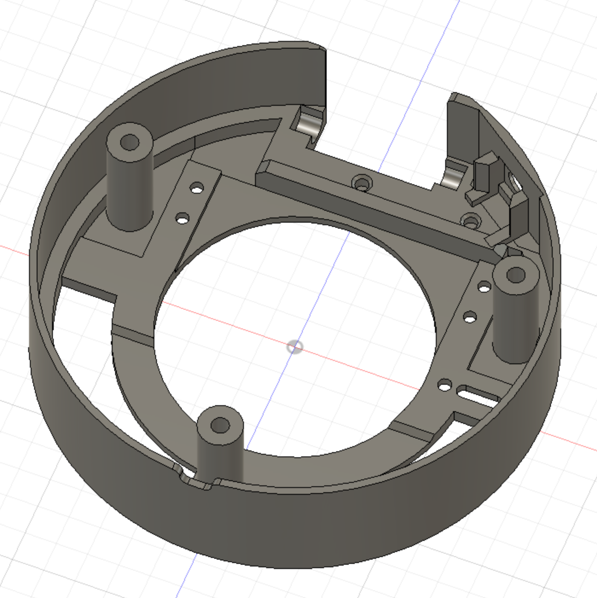
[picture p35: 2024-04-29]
documentation/images/build_images_v1.0.0/1_encoder/base_enc_A.png

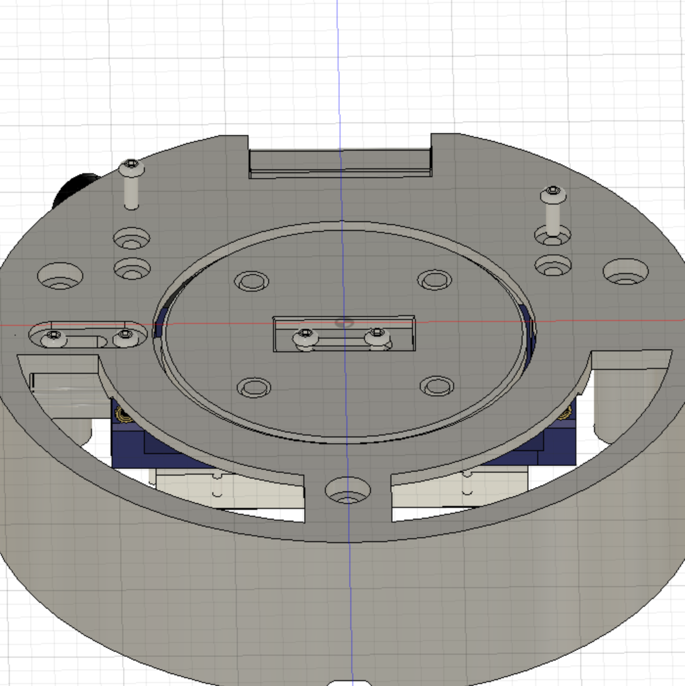
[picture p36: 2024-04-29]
documentation/images/build_images_v1.0.0/4_breadboard/breadboard_D.png

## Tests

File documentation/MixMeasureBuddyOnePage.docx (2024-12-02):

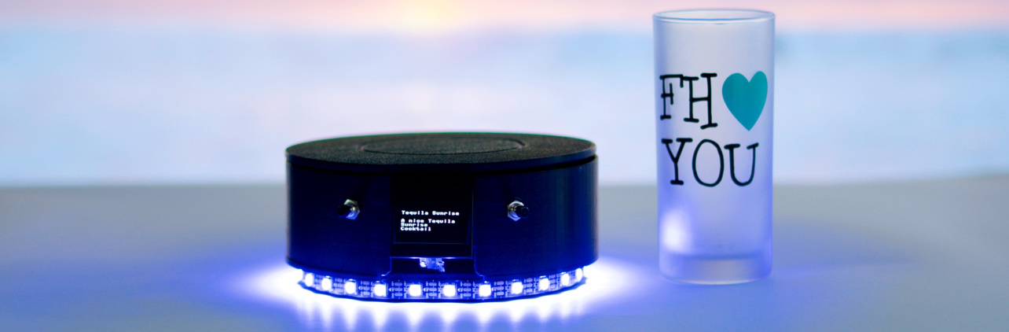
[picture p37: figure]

# MIX MEASURE BUDDY

MixMeasureBuddy is a smart cocktail scale revolutionizes home bartending by offering accurate ingredient measurements and a vast library of cocktail recipes personalized to your liquor collection. Enjoy the art of mixology with ease and precision.

Discover the advanced features that set MixMeasureBuddy apart from traditional kitchen scales.

Discover the advanced features that set MixMeasureBuddy apart from traditional kitchen scales:

- Open-Source MixMeasureBuddy is 100% open-source and can be build using a few simple and cheap parts.
- Offline Usage Recipes are stored offline and locally on the MixMeasureBerry and can be edited using a text editor
- User-Friendly Interface Easily navigate the scale's intuitive interface for effortless cocktail making.
- Customizable Recipes Access a plethora of cocktail recipes tailored to your liquor cabinet for endless mixing possibilities.

## MANUAL

https://github.com/RBEGamer/MixMeasureBuddy

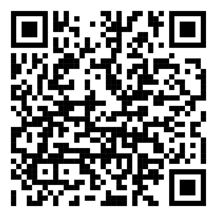
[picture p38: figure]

## FIRST START

- Connect the included USB cable into any USB power source, such as a power-bank
- Wait until the main menu is shown on the display
- Use the rotary knob in order to navigate thought the menus:
  - Rotate left/right – goto next/prev menu
  - Short press – select cocktail / select menu entry
  - Long press [>3s] – abort cocktail procedure / exit current menu

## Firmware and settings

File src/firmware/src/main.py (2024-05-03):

from utime import sleep_us
import uasyncio as aio
from aiobutton import AIOButton
import machine
import helper
from Scales import ScaleInterface
from ledring import ledring
import system_command
# NEEDED FOR ENCODER
from sys import platform
if 'esp' in platform: 
    from rotary_irq_esp import RotaryIRQ
elif 'rp' in platform:
    from rotary_irq_rp2 import RotaryIRQ
else:
    from rotary_irq_pyb import RotaryIRQ


import config
import recipe_loader
import recipe_updater
from ui import ui
import settings
import menu_manager
# PLUGINS
import menu_entry_submenu
import menu_entry_recipe_update
import menu_entry_recipe_editor
import menu_entry_scale
import menu_entry_info
import menu_entry_recipe
import menu_entry_hardwaretest
import menu_entry_calibration
import menu_entry_restore


TIME_ELAPSED_DIVIDER: int = 2
print("main: __entry__")

BUTTON_INDEX_LEFT = 0
BUTTON_INDEX_RIGHT = 1
BUTTON_INDEX_MENU = 2

BUTTON_PRESSED = 0
BUTTON_HOLD = 1
BUTTON_RELEASED = 2

last_left_button_state: int = 0
button_state_dict: list = [-1, -1, -1]
encoder_middle_point: int = 1
current_button_cmd: system_command.system_command = system_command.system_command()
current_button_cmd.type = system_command.system_command.COMMAND_TYPE_NAVIGATION
# GENERATED SYSTEM EVENTS DEPENING ON THE PRESSED BUTTON TO NAVIGATE THOUGHT MENUS
def generate_button_state(_button_index: int, _button_event: int, _button_state: bool):

    if button_state_dict[_button_index] == BUTTON_PRESSED and _button_event == BUTTON_RELEASED:
        if _button_index == BUTTON_INDEX_LEFT:
            current_button_cmd.action = system_command.system_command.NAVIGATION_LEFT
        elif _button_index == BUTTON_INDEX_RIGHT:
            current_button_cmd.action = system_command.system_command.NAVIGATION_RIGHT
        elif _button_index == BUTTON_INDEX_MENU:
            current_button_cmd.action = system_command.system_command.NAVIGATION_ENTER

        menu_manager.menu_manager().process_user_commands(current_button_cmd)

    elif _button_event == BUTTON_HOLD:
        if _button_index == BUTTON_INDEX_LEFT:
            current_button_cmd.action = system_command.system_command.NAVIGATION_EXIT
        elif _button_index == BUTTON_INDEX_RIGHT:
            current_button_cmd.action = system_command.system_command.NAVIGATION_ENTER
        elif _button_index == BUTTON_INDEX_MENU:
            current_button_cmd.action = system_command.system_command.NAVIGATION_EXIT

        
        menu_manager.menu_manager().process_user_commands(current_button_cmd)
    
    button_state_dict[_button_index] = _button_event
   
   
   



if __name__ == "__main__":
    
    # INIT RECIPE LOADER AND INIT SD CARD
    settings.settings().list_files()
    # RECIPE STORAGE
    recipe_loader.recipe_loader().list_recpies()
    # INIT LED RING
    ledring().set_neopixel_full_hsv(ledring().COLOR_PRESET_HSV_H__BLUE)
    # INIT UI
    ui().clear()
    # INIT SCALE
    ScaleInterface().tare()

    # INIT USER INPUT BUTTONS
    left_button_pin: machine.Pin = machine.Pin(config.CFG_BUTTON_LEFT_PIN, machine.Pin.IN, machine.Pin.PULL_UP)
    left_button = AIOButton(lambda btn: not left_button_pin.value())
    left_button.set_hold_ms(config.CFG_USER_LONG_BUTTON_PRESS_TIME)
    # Register button event handlers
    left_button.set_hold_handler(lambda btn: generate_button_state(BUTTON_INDEX_LEFT, BUTTON_HOLD, btn.get_debounced()))   
    left_button.set_press_handler(lambda btn: generate_button_state(BUTTON_INDEX_LEFT, BUTTON_PRESSED, btn.get_debounced()))
    left_button.set_release_handler(lambda btn: generate_button_state(BUTTON_INDEX_LEFT, BUTTON_RELEASED, btn.get_debounced())) 
    
    right_button_pin: machine.Pin = machine.Pin(config.CFG_BUTTON_RIGHT_PIN, machine.Pin.IN, machine.Pin.PULL_UP)
    right_button = AIOButton(lambda btn: not right_button_pin.value())
    right_button.set_hold_ms(config.CFG_USER_LONG_BUTTON_PRESS_TIME)
    # Register button event handlers
    right_button.set_hold_handler(lambda btn: generate_button_state(BUTTON_INDEX_RIGHT, BUTTON_HOLD, btn.get_debounced()))   
    right_button.set_press_handler(lambda btn: generate_button_state(BUTTON_INDEX_RIGHT, BUTTON_PRESSED, btn.get_debounced()))
    right_button.set_release_handler(lambda btn: generate_button_state(BUTTON_INDEX_RIGHT, BUTTON_RELEASED, btn.get_debounced())) 
    

    
    ## REGISTER ENCODER BUTTON EVENTS BY REMAPPING THE ENCODER SWITCH 
    encoder_button_pin: machine.Pin = machine.Pin(config.CFG_ENCODER_SW_PIN, machine.Pin.IN, machine.Pin.PULL_UP)
    #while True:
    #    print(encoder_button_pin.value())
    
    encoder_button = AIOButton(lambda btn: not encoder_button_pin.value())
    encoder_button.set_hold_handler(lambda btn: generate_button_state(BUTTON_INDEX_MENU, BUTTON_HOLD, btn.get_debounced()))   
    encoder_button.set_press_handler(lambda btn: generate_button_state(BUTTON_INDEX_MENU, BUTTON_PRESSED, btn.get_debounced()))
    encoder_button.set_release_handler(lambda btn: generate_button_state(BUTTON_INDEX_MENU, BUTTON_RELEASED, btn.get_debounced())) 
    
    # CONFIGURE ENCODER
    encoder: RotaryIRQ = RotaryIRQ(pin_num_clk=config.CFG_ENCODER_CLK_PIN, pin_num_dt=config.CFG_ENCODER_DT_PIN, min_val=encoder_middle_point-encoder_middle_point, max_val=encoder_middle_point*2, reverse=config.CFG_ENCODER_INVERT, range_mode=RotaryIRQ.RANGE_WRAP)
    encoder.set_current_value(encoder_middle_point)
    # INIT MENU SYSTEM
    
    # ADD RECIPES
    for r in recipe_loader.recipe_loader().list_recpies(_include_description=True):
        filename, name, description = r
        print("adding recipe entry: {}".format(filename))
        # name description are only used for menu entries, recipe will be loaded again by filename
        menu_manager.menu_manager().add_subentries(menu_entry_recipe.menu_entry_recipe(filename, name, description))

    
    
    # ADD FURTHER SYSTEM MENUS
    menu_manager.menu_manager().add_subentries(menu_entry_scale.menu_entry_scale())

    # ADD SYSTEM MENUS
    system_menu: menu_entry_submenu.menu_entry_submenu = menu_entry_submenu.menu_entry_submenu("SYSTEM", "ACCESS SYSTEM SETTINGS")
    system_menu.add_subentries(menu_entry_calibration.menu_entry_calibration())
    system_menu.add_subentries(menu_entry_info.menu_entry_info())
    system_menu.add_subentries(menu_entry_restore.menu_entry_restore())
    if config.CFG_DEBUG:
        system_menu.add_subentries(menu_entry_hardwaretest.menu_entry_hardwaretest())
    
    # ADD RECIPE UPDATE FUNCTIONS
    if recipe_updater.recipe_update_helper.has_network_capabilities():
        system_menu.add_subentries(menu_entry_recipe_update.menu_entry_recipe_update())
        # EDITOR IS CURRENTLY UNDER DEVELOPMENT
        if config.CFG_DEBUG:
            system_menu.add_subentries(menu_entry_recipe_editor.menu_entry_recipe_editor())


    menu_manager.menu_manager().add_subentries(system_menu)

    async def main_task():
        
        last_scale_update = helper.millis()
        last_timer_update = helper.millis()

        # DECLEARE SOME SYSTEM STATE MESSAGES IN ORDER TO ACVOID REALLOCATION
        current_scale_cmd: system_command.system_command = system_command.system_command(system_command.system_command.COMMAND_TYPE_SCALE_VALUE, system_command.system_command.SCALE_CURRENT_VALUE)
        current_timertick_cmd: system_command.system_command = system_command.system_command(system_command.system_command.COMMAND_TYPE_TIMER_IRQ, system_command.system_command.TIMER_TICK)

        # CREATE TASKS FOR USER INPUT
        task_left = aio.create_task(left_button.coro_check())
        task_right = aio.create_task(right_button.coro_check())
        task_menu = aio.create_task(encoder_button.coro_check())
        
        current_encoder_cmd: system_command.system_command = system_command.system_command()
        current_encoder_cmd.type = system_command.system_command.COMMAND_TYPE_NAVIGATION
       
        while True:
            await aio.sleep_ms(1)


            # QUERY ENCODER AND DETERM USER INTPUT STATE
            current_encoder_value = encoder.value()
            if current_encoder_value != encoder_middle_point:
                current_encoder_cmd.value = current_encoder_value
                
                if current_encoder_value > encoder_middle_point:
                    encoder.set_current_value(encoder_middle_point)
                    current_encoder_cmd.action = system_command.system_command.NAVIGATION_LEFT
                    menu_manager.menu_manager().process_user_commands(current_encoder_cmd)
                elif current_encoder_value < encoder_middle_point:
                    encoder.set_current_value(encoder_middle_point)
                    current_encoder_cmd.action = system_command.system_command.NAVIGATION_RIGHT
                    menu_manager.menu_manager().process_user_commands(current_encoder_cmd)
              

            # PERIODIC READ OF THE SCALE
            if  abs(last_scale_update - helper.millis()) > (10/TIME_ELAPSED_DIVIDER):
                last_scale_update = helper.millis()
                # UPDATE SCALE VALUE AND SEND TO PROCESS
                current_scale_cmd.value = ScaleInterface().get_current_weight()
                menu_manager.menu_manager().process_system_commands(current_scale_cmd)

            # SYSTEM TICK TO IMPLEMENT TIMERS SUCH AS WAITING FOR X SECONDS IN RECIPES
            if  abs(last_timer_update - helper.millis()) > (1000/TIME_ELAPSED_DIVIDER):
                current_timertick_cmd.value = abs(last_timer_update - helper.millis())
                menu_manager.menu_manager().process_system_commands(current_timertick_cmd)
                last_timer_update = helper.millis()

    aio.run(main_task())

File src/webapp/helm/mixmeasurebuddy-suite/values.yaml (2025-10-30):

replicaCount: 1

imagePullSecrets: []

backend:
  image:
    repository: mixmeasurebuddy-suite-backend
    tag: latest
    pullPolicy: IfNotPresent
  env:
    port: 4000
    recipeStorage: /data/systems
    recipeDbPath: /data/mixmeasurebuddy.sqlite
  readinessProbe:
    path: /
    port: 4000
    initialDelaySeconds: 5
    periodSeconds: 10
  livenessProbe:
    path: /
    port: 4000
    initialDelaySeconds: 15
    periodSeconds: 20
  resources: {}

frontend:
  image:
    repository: mixmeasurebuddy-suite-frontend
    tag: latest
    pullPolicy: IfNotPresent
  env:
    nextPublicBackendUrl: /api
  readinessProbe:
    path: /
    port: 80
    initialDelaySeconds: 10
    periodSeconds: 5
  livenessProbe:
    path: /
    port: 80
    initialDelaySeconds: 30
    periodSeconds: 10
  resources: {}

proxy:
  image:
    repository: mixmeasurebuddy-suite-proxy
    tag: latest
    pullPolicy: IfNotPresent
  port: 80
  readinessProbe:
    path: /
    port: 80
    initialDelaySeconds: 5
    periodSeconds: 5
  livenessProbe:
    path: /
    port: 80
    initialDelaySeconds: 15
    periodSeconds: 15
  resources: {}

service:
  type: ClusterIP
  port: 80

persistence:
  enabled: true
  existingClaim: ""
  accessModes:
    - ReadWriteOnce
  size: 1Gi
  storageClass: ""

nodeSelector: {}

tolerations: []

affinity: {}

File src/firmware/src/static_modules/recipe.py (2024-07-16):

class USER_INTERACTION_MODE:
    UNKNOWN = -1
    SCALE = 0
    CONFIRM = 1
    WAIT = 2

class ingredient:

    name: str = ""
    amount: int = -1
    id: int = 0
    unit: str = ""

    def __init__(self, _name: str, _amount: int = -1, _id: int = 0, _unit: str = ""):
        self.name = _name
        self.amount = _amount
        self.id = _id
        self.unit = _unit


class recipe_step:


    @staticmethod
    def create_scale_step(_ingredient_name: str, _target_value: int,  _current_step_text: str = ""):
        return recipe_step(_action=recipe.USER_INTERACTION_MODE.SCALE, _ingredient_name=_ingredient_name, _current_step_text=_current_step_text, _target_value = _target_value)

    @staticmethod
    def create_confirm_step(_ingredient_name: str, _current_step_text: str):
        return recipe_step(_action=recipe.USER_INTERACTION_MODE.CONFIRM, _ingredient_name = _ingredient_name, _current_step_text = _current_step_text, _target_value = -1)

    @staticmethod
    def create_wait_step(_current_step_text: str, _target_value: int):
        return recipe_step(_action=recipe.USER_INTERACTION_MODE.WAIT, _ingredient_name="", _current_step_text = _current_step_text, _target_value = _target_value)



    action: USER_INTERACTION_MODE = USER_INTERACTION_MODE.UNKNOWN
    ingredient_name: str = ""
    current_step_text: str = "---"
    target_value: int = 0


    def __init__(self, _action: USER_INTERACTION_MODE = USER_INTERACTION_MODE.UNKNOWN, _ingredient_name: str = "", _current_step_text: str = "---", _target_value: int = 0):
        self.action = _action
        self.ingredient_name = _ingredient_name
        self.current_step_text = _current_step_text
        self.target_value = _target_value

        if self.target_value is None:
            self.target_value = 0

    def to_dict(self) -> dict:
        return {
            'action': self.action,
            'ingredient' : self.ingredient_name,
            'amount': self.target_value,
            'text': self.current_step_text
            }
    
    def from_dict(self, _step_dict: dict):
        if 'action' in _step_dict:
            self.action = _step_dict['action']
        if 'ingredient' in _step_dict:
            self.ingredient_name = _step_dict['ingredient']
        if 'amount' in _step_dict:
            self.target_value = _step_dict['amount']
            
        if 'text' in _step_dict:
            self.current_step_text = _step_dict['text']

        if self.target_value is None:
            self.target_value = 0
class recipe:
    
    name: str = ""
    description: str = ""
    version: str = "1.0.0"
    filename: str = ""
    steps: list[recipe_step] = []
    categories: list[str] = ["everything"]
    valid: bool = False

    current_step_index: int = -1

    def __init__(self, _name: str = "Recipe", _description:str = "A nice cocktail", _version: str = "1.0.0", _categories: list[str] = ["everything"]) -> None:
        self.name = _name
        self.description = _description
        self.version = _version

        self.filename = self.name.replace(" ", "_").replace(".recipe", "")
        self.filename = self.filename + ".recipe"

        self.categories = _categories
        if len(self.categories) <= 0:
            self.categories.append("everything")

       
        self.steps = []
        self.reset_steps()

   

    def add_step(self, _step: recipe_step):
        self.steps.append(_step)
           

    
    def from_dict(self, _json_dict: dict) -> bool:
        if 'name' in _json_dict:
            self.name = _json_dict['name']
        if 'description' in _json_dict:
            self.description = _json_dict['description']
        if 'version' in _json_dict:
            self.version = _json_dict['version']

        if 'steps' in _json_dict:
            steps = _json_dict['steps']
            self.steps = []
            if len(steps) > 0:
                for s in steps:
                    step: recipe_step = recipe_step()
                    step.from_dict(s)
                    self.add_step(step)
        
      
        self.filename = self.name.replace(" ", "_").replace(".recipe", "")
        self.filename = self.filename + ".recipe"
        self.valid = True
        
    def to_dict(self, _add_filename_as_root_key: bool = False) -> dict:
        ret: dict = {}
        ret[self.filename] = {
            'name': self.name,
            'description': self.description,
            'version': self.version,
            'filename': self.filename
        }
        # ADD STEPS
        ret[self.filename]['steps'] = []
        for s in self.steps:
            ret[self.filename]['steps'].append(s.to_dict())

    
        if _add_filename_as_root_key:
            return ret

        return ret[self.filename]


    def is_valid(self) -> bool:
        return self.valid


    def get_description(self) -> str:
        return self.description

    def get_categories(self) -> list[str]:
        return self.categories

    


    def get_recipe_information(self) -> tuple[str, str]:
        return (self.name, self.description)
    

    def switch_next_step(self):
        if len(self.steps) < 0:
            self.current_step_index = -1
            return
        self.current_step_index = (self.current_step_index + 1) % len(self.steps)
                  
    def switch_prev_step(self):
        if len(self.steps) < 0:
            self.current_step_index = -1
            return
        self.current_step_index = (self.current_step_index - 1) % len(self.steps)

    def reset_steps(self):
        if len(self.steps) < 0:
            self.current_step_index = -1
            return
        self.current_step_index = 0
    

    def get_ingredients(self) -> list[ingredient]:
        res: list[ingredient] = []
        ingredient_dict: dict = {}
        # DETERM THE TOTAL INGREDIENT AMOUNT OVER ALL STEPS
        # TODO REWORK
        for s in self.steps:
            # SKIP USER ACTIONS WITH NO PHYSICAL INGREDIENTS
            if s.action == USER_INTERACTION_MODE.WAIT or s.action == USER_INTERACTION_MODE.UNKNOWN:
                continue


            if not s.ingredient_name in ingredient_dict:
                ingredient_dict[s.ingredient_name] = {'amount': 0, 'unit': ''}
                
                if s.action == USER_INTERACTION_MODE.SCALE:
                    ingredient_dict[s.ingredient_name]['unit'] = 'g'
                elif s.action == USER_INTERACTION_MODE.CONFIRM:
                    ingredient_dict[s.ingredient_name]['unit'] = 'x'

            if s.target_value > 0:
                ingredient_dict[s.ingredient_name]['amount'] = ingredient_dict[s.ingredient_name]['amount'] + s.target_value

            
        # REASSEMBLE DICT INTO ARRAY
        index: int = 0
        for k, v in ingredient_dict.items():
            res.append(ingredient(k, v['amount'], index, v['unit']))
            index = index +1
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

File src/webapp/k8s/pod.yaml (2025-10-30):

apiVersion: v1
kind: Pod
metadata:
  name: mixmeasurebuddy-suite
  labels:
    app: mixmeasurebuddy-suite
spec:
  containers:
    - name: backend
      image: mixmeasurebuddy-suite-backend:latest
      imagePullPolicy: IfNotPresent
      env:
        - name: PORT
          value: '4000'
        - name: RECIPE_STORAGE
          value: /data/systems
        - name: RECIPE_DB_PATH
          value: /data/mixmeasurebuddy.sqlite
      ports:
        - containerPort: 4000
      readinessProbe:
        httpGet:
          path: /
          port: 4000
        initialDelaySeconds: 5
        periodSeconds: 10
      livenessProbe:
        httpGet:
          path: /
          port: 4000
        initialDelaySeconds: 15
        periodSeconds: 20
      volumeMounts:
        - name: mixmeasurebuddy-suite-backend-data
          mountPath: /data
    - name: frontend
      image: mixmeasurebuddy-suite-frontend:latest
      imagePullPolicy: IfNotPresent
      env:
        - name: NEXT_PUBLIC_BACKEND_URL
          value: http://localhost:4000
      ports:
        - containerPort: 80
      readinessProbe:
        httpGet:
          path: /
          port: 80
        initialDelaySeconds: 10
        periodSeconds: 5
      livenessProbe:
        httpGet:
          path: /
          port: 80
        initialDelaySeconds: 30
        periodSeconds: 10
    - name: proxy
      image: mixmeasurebuddy-suite-proxy:latest
      imagePullPolicy: IfNotPresent
      ports:
        - containerPort: 80
      readinessProbe:
        httpGet:
          path: /
          port: 80
        initialDelaySeconds: 5
        periodSeconds: 5
      livenessProbe:
        httpGet:
          path: /
          port: 80
        initialDelaySeconds: 15
        periodSeconds: 15
  volumes:
    - name: mixmeasurebuddy-suite-backend-data
      emptyDir: {}

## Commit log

2023-11-01 added calibration mode
2023-11-07 scale working + tare
    [mmb_schematic.fzz]
2023-12-24 typo fix in build script
    [st7789.py]
2024-04-20 button management, settings, recipe update
2024-04-21 leds and recipe menu entires working
2024-04-22 working on reworked recipe format
    [menu_entry_recipe.py, menu_entry_recipe_editor.py, recipe.py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]
2024-04-24 added updated schematic
    [mmb_schematic.fzz, mmb_schematic_buttons.fzz, mmb_schematic_encoder.fzz]
2024-04-25 archived firmware for 0.9.0 added
    [display_clamp_SSH1106.stl, display_mount_SSH1106.stl, inner_cellplate.stl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]
2024-04-25 working firmware v0.9.1
    fixed calibration plugin
    [mmb_schematic_encoder_sd.fzz]
2024-04-27 fixed scale menu - v0.9.8
    [main.py, menu_entry_calibration.py, menu_entry_hardwaretest.py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]
2024-04-29 added new stls
    [bottom.stl, breadboard_mount.stl, cellplate.stl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]
2024-04-29 added new exported stls for v1.0.0
    [Display_OLED_SSD1306_1.3inch v1.f3d, Display_OLED_SSD1306_1.3inch v1.step, Insert M3 D5 L5mm v1.step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]
2024-05-03 fixed ring body
    [ring.step, ring.stl]
2024-05-03 another fixed ring body version
    [MixMeasureBuddy.step, ring.step, ring.stl]
2024-05-03 new cellplates
    [Display_OLED_SSD1306_1.3inch v1.f3d, MixMeasureBuddy.step, cellplate.step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]
2024-05-21 fixed encoder clamp
    [encoder_clamp.step, encoder_clamp.stl]
2024-12-02 added rp pico 2350 support
2025-10-26 reworked frontend to be a static site instead of using an api
    [config.cfg]
